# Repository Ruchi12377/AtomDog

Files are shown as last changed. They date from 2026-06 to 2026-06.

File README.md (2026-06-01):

# Stack-Wan-Chan (Atom Dog)

StackChan Minimalをベースにした犬型AIロボを動かすためのプロジェクトです。

M5Stack AtomS3R AI Chatbot キット、PCA9685、8 個の SG90 サーボ、3D プリントした犬型ボディを組み合わせ、ローカル AI サーバーと連携してペットの様に振舞います。

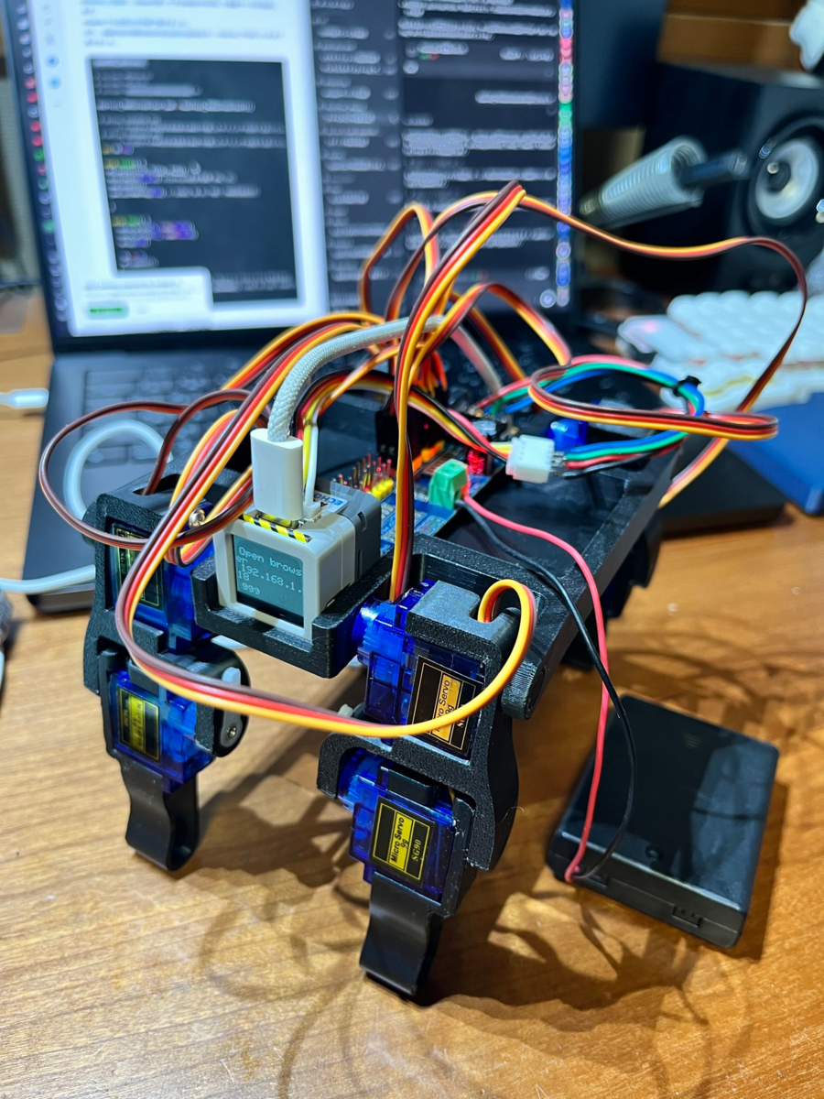
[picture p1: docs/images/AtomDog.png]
Stack-Wan-Chan


## 概要

AtomS3R 上で動く 4 足歩行 AI ロボットです。

本体側は Wi-Fi、録音、TTS 再生、画面表示、サーボモーションを担当します。音声認識、LLM、音声合成などの重い AI 処理は、PC やスマートフォンなどで起動した外部サーバーに任せる構成です。

## 主な機能

- Wi-Fi 設定ポータル
- AtomS3R 画面への Miro 表情表示
- ローカル Whisper サーバーによる音声認識
- OpenAI 互換 API 経由のローカル LLM 会話
  - llama.cpp
  - LM Studio
  - Ollama
- Piper / piper-plus サーバーによる音声合成
- `walk_only_sample/robot_viewer.html` によるモーション確認・編集 (実験的機能)
- `walk_only_sample/` による PCA9685 + 8 サーボの 4 足歩行テスト (実験的機能)

## ToDo

- 会話に合わせた犬型 4 足ボディのサーボモーション
  - 起き上がり / うなずき / 首振り / アイドル動作
- 会話プログラムとモーションプログラムの統合 (ASAP)

## 部品リスト

| 部品 | 数量 | メモ |
| --- | ---: | --- |
| [ATOMS3R AI Chatbot キット](https://www.switch-science.com/products/10487) | 1 | AtomS3R と音声ベースの中心部 |
| [PCA9685 16ch PWM サーボドライバ](https://www.switch-science.com/products/961) | 1 | 8 個のサーボを制御 |
| [マイクロサーボ 9g SG90](https://akizukidenshi.com/catalog/g/g108761/) | 8 | 4 足分 |
| [GROVE 互換ケーブル](https://www.switch-science.com/products/5213) | 1 | AtomS3R 側との接続用 |
| [ピンソケット 1x6](https://www.switch-science.com/products/2016) | 1 | PCA9685 周辺の接続用 |
| [電池ボックス](https://akizukidenshi.com/catalog/g/g100311/) | 1 | サーボ用外部電源 |
| [GROVE 4 ピンコネクタ](https://www.switch-science.com/products/1122) | 1 | ケーブル作成用 |
| [M2x5mm ねじ](https://akizukidenshi.com/catalog/g/g115887/) | 適量 | 3D プリント部品とサーボ固定用 |
| 配線ケーブル | 適量 | 赤・黒・その他 2 色、AWG24-26 程度を推奨 |

サーボ電源は AtomS3R の USB 給電とは分けてください。PCA9685、サーボ電源、AtomS3R 側の GND は共通にします。

## 印刷する部品

犬型ボディは 3D プリント部品を使います。STL は `hardware/cases/` にあります。

| STL | 印刷数 | 用途 |
| --- | -----: | ---- |
| `hardware/cases/Body_x1.stl` | 1 | 胴体 |
| `hardware/cases/Leg_L_x2.stl`  | 2 | 左脚 |
| `hardware/cases/Leg_R_x2.stl`  | 2 | 右脚 |
| `hardware/cases/Foot_L_x2.stl` | 2 | 左足 |
| `hardware/cases/Foot_R_x2.stl` | 2 | 右足 |

印刷後、サーボの向き、ホーンの初期角度、脚の可動範囲を確認してから組み立てます。素材やスライサー設定は手元のプリンタに合わせて調整してください。
PLAを使ってBambu Lab A1を使って印刷しました。

## AI サーバー

このリポジトリには、AI モデル、AI サーバーバイナリ、TTS エンジン、音声モデル、音声ライブラリは含まれていません。

必要に応じて、次のサービスを別途起動してください。

- whisper.cpp: 音声認識
- llama.cpp / LM Studio / Ollama: LLM 会話
- piper-plus: 音声合成
- VOICEVOX 互換アダプター 任意

個人的にはGUIでよしなに操作できるんでLM Studioがおすすめです。モデルは`gemma-4-E2B-it-GGUF/gemma-4-E2B-it-Q4_K_S`を使ってます。
サーバー用のパソコンはMacBook Pro M5 / RAM 24GBです。前述のモデルだと60~Token / secで動くので爆速でレスポンスが帰ってきます。

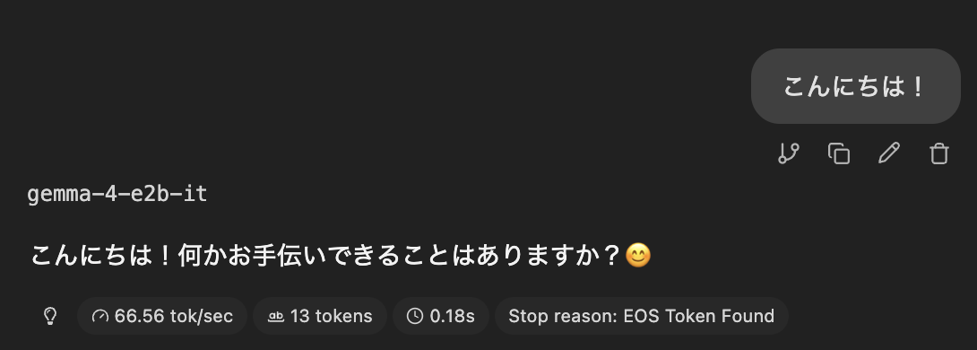
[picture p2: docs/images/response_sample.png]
LM Studio response sample


AtomS3R からは Web 設定画面で各サーバーの IP アドレス、ポート、モデル名などを設定します。

## ビルド

メインファームウェア:

```sh
pio run
```

書き込み:

```sh
pio run --target upload
```

シリアルモニタ:

```sh
pio device monitor
```

現在の `platformio.ini` は AtomS3R / Arduino-ESP32 Core v2 系を前提にしています。サーボ制御を使うため `-DENABLE_SERVO` が有効です。

4 足歩行だけを試す場合は `walk_only_sample/` を使います。

```sh
cd walk_only_sample
pio run
```

`walk_only_sample` は AtomS3R の GROVE/HY2.0-4P 端子から PCA9685 を I2C 接続し、8 個の SG90 を動かす最小テスト兼モーション調整用ファームウェアです。

## 初回起動

1. AtomS3R を起動します。
2. Wi-Fi 未設定の場合は設定用 AP が立ち上がります。
3. 画面に表示される SSID または URL にアクセスします。
4. Wi-Fi と AI サーバー設定を保存します。
5. 再起動後、Miro がネットワーク経由で AI サーバーに接続します。

## サーボについて

PCA9685と8個のSG90で犬型4足ボディを動かします。

`walk_only_sample` の配線:

```text
Atom G                 -> PCA9685 GND
Atom 5V                -> PCA9685 VCC
Atom GROVE white / G1  -> PCA9685 SDA
Atom GROVE yellow / G2 -> PCA9685 SCL

External 5V +          -> PCA9685 V+
External 5V -          -> PCA9685 GND
```

AtomS3R 側 GND、PCA9685 GND、サーボ用外部電源 GND は必ず共通にします。

起動時に短いセルフテストを行い、センター位置、上下、左右の動作を確認します。サーボが動かない場合は、次を確認してください。

- サーボ用電源が接続されているか
- GND が AtomS3R 側と共通になっているか
- PCA9685 の SDA / SCL の配線が正しいか
- サーボの向きと可動範囲が機構に合っているか

サーボは USB 給電だけでは電流が足りないことがあります。安定した外部電源を使ってください。

メインファームウェア側の簡易サーボ機能は GPIO2 / GPIO1 の 2 サーボ制御を前提にしています。4 足歩行の調整や動作確認は `walk_only_sample` を使ってください。

## VOICEVOX TTS 任意

StackChan Minimal Dog Edition は、外部 TTS サーバーとして VOICEVOX 互換アダプターへ接続できます。

本リポジトリには、VOICEVOX、VOICEVOX Engine、VOICEVOX Core、音声モデル、音声ライブラリ、VOICEVOX インストーラーは含まれていません。

VOICEVOX 音声を利用する場合は、ユーザー自身が公式配布元から VOICEVOX を別途インストールし、VOICEVOX ソフトウェア利用規約および各音声ライブラリの利用規約に従ってください。

クレジット表記例:

- VOICEVOX:ずんだもん
- VOICEVOX:四国めたん

StackChan Minimal Dog Edition は、VOICEVOX および各音声ライブラリの権利者による公式製品・公認製品ではありません。

## ライセンス

このプロジェクトは Apache License 2.0 で公開しています。

サードパーティライブラリのライセンスは `third_party_licenses/` を確認してください。

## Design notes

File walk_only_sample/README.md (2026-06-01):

# PCA9685 Servo Sweep Test for AtomS3R

AtomS3R + PCA9685の最小テスト用ファームウェアおよびビジュアル操作ツールです。

- 起動時にPCA9685の全16チャンネルを90度へ移動します。
- 画面タップ、または本体ボタンで、全16チャンネルを `90 -> 0 -> 90 -> 180 -> 90` の順に1回動かします。
- WiFi接続後、AtomS3Rの画面に表示されたIPへブラウザでアクセスすると、CH0〜7をスライダーで指定できます。
- 対角歩行: 右前+左後 → 左前+右後 を交互に出し、接地側で軽く押す9フレームのシーケンス（`walk` / `walk_fast`）。
- ボタンA: Walk loop の開始/停止。
- AtomS3R本体のGROVE/HY2.0-4P端子を使い、`SDA=GPIO1` / `SCL=GPIO2` に固定しています。

## Robot Viewer (WebGL 3Dビューア)

`pca9685_servo_sweep_test/robot_viewer.html` をブラウザで開いて使用します。
- 接続ボタンを押すと、デバイス本体に保存されているモーション（`walk`）を自動で読み込み、タイムライン上に展開します（HTML側から歩行プリセットを毎回アップロードする送信処理は廃止されました）。
- タイムラインから各コマのミリ秒数調整や、ドラッグによる関節角度編集が可能です。
- UIは視認性の高いライトテーマになっています。

## Web Control

WiFi configuration:

```text
cp walk_only_sample/src/local_config.example.h walk_only_sample/src/local_config.h
```

Then edit `walk_only_sample/src/local_config.h` with your local SSID and password.

HTTP API (モーションは PSRAM + LittleFS `/m/{name}.json` に保存):

```text
POST /upload?name=walk          # body: motion JSON
GET  /motions                   # 一覧
GET  /motion?name=walk          # JSON 取得
GET  /play?name=walk            # 1回再生
GET  /loop/start?name=walk      # ループ再生
GET  /loop/start?name=walk_fast # 速い歩行
GET  /loop/stop                 # 停止
GET  /sit/play  GET /stand      # 既定 sit / stand モーション
GET  /sequence?name=walk        # 互換 (GET/POST)
```

モーション JSON 例:

```json
{
  "name": "my_walk",
  "loopStartFrame": 3,
  "frames": [
    { "ms": 120, "angles": [56,108,112,78,68,102,124,72] },
    { "ms": 130, "angles": [54,128,112,84,68,96,126,52] }
  ]
}
```

`angles` は CH0〜7（右前膝/股、右後膝/股、左前膝/股、左後膝/股）。初回起動で flash が空なら `walk` / `walk_fast` / `sit` / `stand` を自動生成します。

## Wiring

PCA9685 logic side:

```text
Atom G   -> PCA9685 GND
Atom 5V  -> PCA9685 VCC
Atom GROVE white / G1 -> PCA9685 SDA
Atom GROVE yellow / G2 -> PCA9685 SCL
```

Servo power:

```text
External 5V + -> PCA9685 V+
External 5V - -> PCA9685 GND
```

Atom側GND、PCA9685 GND、サーボ電源GNDは共通にしてください。

## Commands

```bash
cd /Users/ruchi/Documents/GitHub/StackChan_Minimal/pca9685_servo_sweep_test
pio run -e m5stack-atoms3
pio run -e m5stack-atoms3 -t upload --upload-port /dev/cu.usbmodem1101
pio device monitor -p /dev/cu.usbmodem1101 -b 115200
```

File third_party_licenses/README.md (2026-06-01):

# Third-party licenses

This directory contains license information for third-party libraries used by StackChan Minimal.

このディレクトリには、StackChan Minimal が利用するサードパーティライブラリのライセンス情報を配置しています。

## Included license texts

| Component | License | Purpose | Source |
|---|---|---|---|
| M5Stack-Avatar | See `lib/M5Stack-Avatar/LICENSE.txt` | Avatar face rendering | Bundled local library |

## Optional external tools not included in this repository

StackChan Minimal can be configured to connect to external TTS servers such as piper-plus or a user-provided VOICEVOX-compatible adapter.

VOICEVOX, VOICEVOX Engine, VOICEVOX Core, voice models, voice libraries, and VOICEVOX installers are not included in this repository.

If you use VOICEVOX-generated audio, please install VOICEVOX separately from its official distribution source and follow the VOICEVOX software terms and each voice library's terms.

Credit examples:

- VOICEVOX:ずんだもん
- VOICEVOX:四国めたん

StackChan Minimal is not affiliated with or endorsed by VOICEVOX or the rights holders of the voice libraries.

## Notes

StackChan Minimal itself is licensed under the Apache License 2.0.

Some libraries used by PlatformIO may be downloaded during build time according to `platformio.ini`.
Please refer to each library's upstream repository for the latest license information.

## 日本語メモ

StackChan Minimal 本体は Apache License 2.0 で公開しています。

このディレクトリには、本体とは別ライセンスで提供されるサードパーティライブラリのライセンス文を配置します。

VOICEVOX、VOICEVOX Engine、VOICEVOX Core、音声モデル、音声ライブラリ、VOICEVOXインストーラーは、このリポジトリには含めていません。
VOICEVOX音声を利用する場合は、VOICEVOXソフトウェア利用規約および各音声ライブラリの利用規約を確認してください。

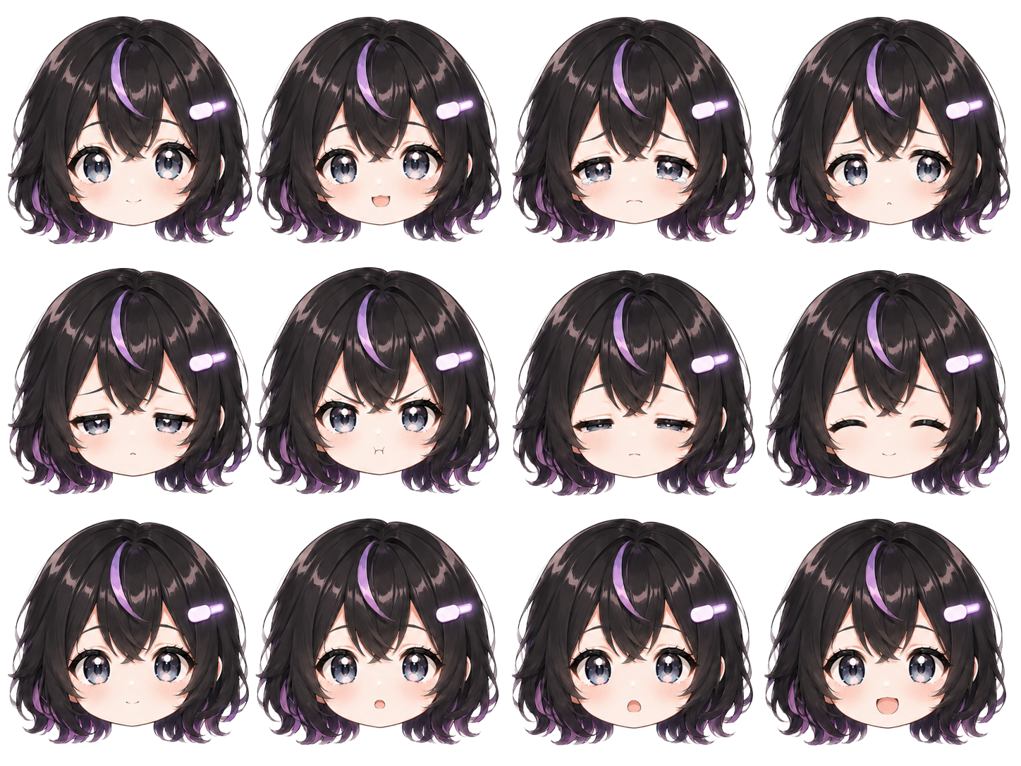
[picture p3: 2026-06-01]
incbin/faces/faces.png

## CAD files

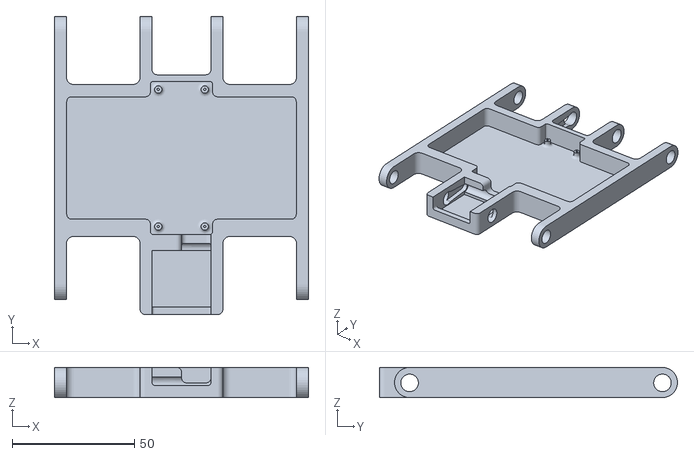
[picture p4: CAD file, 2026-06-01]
hardware/cases/Body_x1.stl
103.8 x 121.8 x 12.3

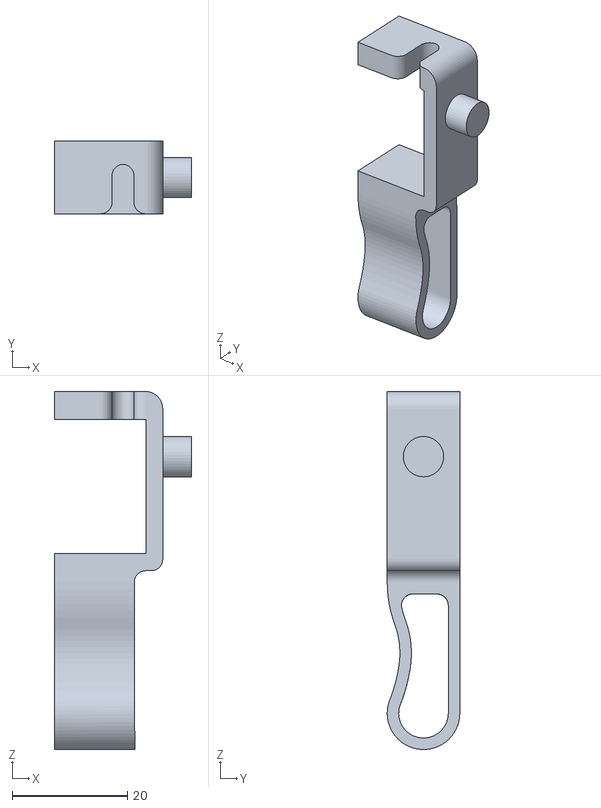
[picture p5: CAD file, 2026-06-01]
hardware/cases/Foot_L_x2.stl
23.8 x 12.6 x 62.1

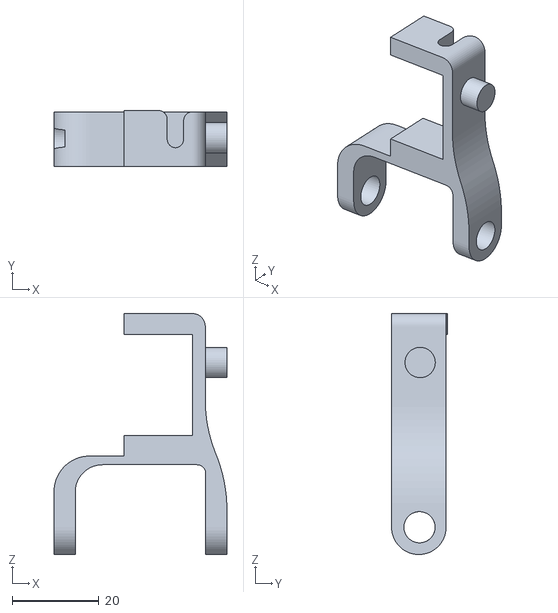
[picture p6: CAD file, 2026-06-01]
hardware/cases/Leg_L_x2.stl
39.9 x 12.9 x 55.6

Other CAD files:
hardware/cases/Foot_R_x2.stl
hardware/cases/Leg_R_x2.stl

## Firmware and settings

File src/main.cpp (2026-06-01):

/***
 - GitHub StackChan_Minimal

 <For AI server tools>
 - Speech-to-Text
 1. whisper.cpp
    https://github.com/ggml-org/whisper.cpp

 - Local LLM (OpenAI Compatibility API)
 1. llama.cpp
    https://github.com/ggml-org/llama.cpp
 2. LM Studio
    https://lmstudio.ai/
 3. ollama
    https://github.com/ollama/ollama

 - Text-to-Speech
 1. piper-plus
    https://github.com/ayutaz/piper-plus

***/

#include <Arduino.h>
#include <esp_system.h>
#include <M5Unified.h>
#include <nvs.h>          // Add for Web Setting
#include <Avatar.h>       // Add for M5 avatar
#include "MiroSpriteFace.h"
#include <HTTPClient.h>
#include <WiFiClientSecure.h>
#include <WiFi.h>            // Wi-Fi control (explicit include)
#include <DNSServer.h>       // For http://m5stack/ in AP mode
#include <ESPmDNS.h>         // For http://m5stack.local/ fallback
#include <ArduinoJson.h>
#include "AudioWhisper.h"
#include "Whisper_d_cpp.h"
#include <deque>
#include <atomic>
#include <ESP32WebServer.h> // Add for Web Setting
#include <Preferences.h>    // Add for nvs management

#include <mbedtls/base64.h>
#include <memory>               // std::unique_ptr 用

// 前方宣言（定義はsetup()より前にあるが、関数より前に呼ぶ箇所があるため）
static void initSpeakerOnce();
static void ensureSpeakerActive();
static void markSpeakerEndedByAudioWhisper();
static bool speak_piper_http(const String& text, bool allow_cancel);
static bool speak_piper_http_chunked(const String& text, bool allow_cancel);
static std::deque<String> splitForPiperTTS(const String& text, size_t maxChars = 60);
// Phase 3-A: 会話×モーション制御ヘルパー（handle_api_estop等から呼ばれるため前方宣言）
static void motion_on_conversation_start();
static void motion_on_conversation_end();
static void motion_force_stop();
static void ttsTaskFunc(void* arg);
static bool enqueueTtsJob(const String& text, uint8_t expr, bool allow_cancel, bool is_final);
static void requestAvatarUpdate(const String& text, uint8_t expr);
static void applyPendingAvatarUpdate();
static void clearPendingTtsQueue();
// speak_piper_http is defined later (Piper TTS over HTTP)

// nvs
Preferences preferences;

// ===== STT over HTTP (whisper.cpp server) =====
static String WHISPER_SERVER_IP   = "192.168.11.2";   // Whisper.cpp サーバIP (Webメニューで変更可)
static uint16_t WHISPER_SERVER_PORT = 8081;           // Whisper.cpp サーバポート (Webメニューで変更可)
static String WHISPER_SERVER_PATH  = "/inference";    // ★追加: Whisper API パス（NVS保存対象）

// ===== TTS over HTTP (Piper on Termux) =====
static String PIPER_TTS_IP = "192.168.11.2";   // Termux device IP (Webメニューで変更可)
static uint16_t PIPER_TTS_PORT = 5000;         // FastAPI/uvicorn port (Webメニューで変更可)
static float PIPER_TTS_GAIN = 2.00f;           // TTS PCM gain before speaker output
static float PIPER_TTS_LENGTH_SCALE = 1.00f;   // ★追加: 話速 (0.5=速い / 1.0=標準 / 2.0=遅い)
static std::atomic<bool> g_piper_tts_playing{false}

;

// ===== TTS Task (PR1): Core 0 に再生処理を分離 =====
struct TtsJob {
  char*   text;         // ヒープ確保、ttsTask 側で free する
  bool    allow_cancel;
  bool    is_final;
  uint8_t expression;   // Expression enum を uint8_t で格納
};

static QueueHandle_t       g_ttsQueue         = nullptr;
static TaskHandle_t        g_ttsTaskHandle    = nullptr;
static std::atomic<int>    g_tts_pending_jobs{0};
static std::atomic<bool>   g_tts_cancel_requested{false};

// ===== PR2-C: Avatar update request (loop() 側で実反映) =====
static std::atomic<uint8_t> g_avatar_expr_pending{0};  // 0 = Neutral
static std::atomic<bool>    g_avatar_update_requested{false};
static SemaphoreHandle_t    g_avatar_text_mutex = nullptr;
static String               g_avatar_text_pending = "";
static SemaphoreHandle_t    g_display_mutex = nullptr;
static MiroSpriteFace*      g_miro_sprite_face = nullptr;

// ===== Piper/TTS test flags (temporary) =====
static bool g_test_piper_direct_mode = false;   // true: start_talking()でLLMを通さず固定文を直接Piper再生
static bool g_test_disable_history   = true;    // true: exec_chatGPT()で会話履歴を使わず今回の質問だけ送る
static bool g_test_run_direct_once   = false;   // true: setup()完了後に固定文Piperテストを1回だけ自動実行

// ===== Gemma 4 Audio Direct Reply test flag =====
// true : 音声をGemma 4 E4Bへ直接渡し、文字起こしではなく会話応答を返させる
// false: 従来どおり Gemma 4 Audio STT → 通常LLM応答 → TTS
static bool g_gemmaAudioDirectReplyMode = true;

// (legacy UI vars) voice volume/speed
uint8_t PiperPlus_voice_volume = 120;           // 会話音量(Default:120)
uint8_t PiperPlus_voice_speed_legacy = 100;     // 廃止予定: 旧UI互換用（Piper-plusでは未使用）

// ===== VAD calibration async request =====
static volatile bool  g_vad_calibration_requested = false;
static volatile bool  g_vad_calibration_done = false;
static volatile bool  g_vad_calibration_success = false;
static String         g_vad_calibration_result = "";

// ===== リレー（他個体への会話受け渡し）用 =====
String   g_relay_origin_question = "";   // 最初のユーザ質問（ホップ不変）
String   g_relay_previous_answer = "";   // 直前個体の回答（ホップごとに上書き）
int      g_relay_hop             = 0;    // 現在のホップ数（起点受信前=0, 起点→B送信時点で1）
String   g_relay_origin          = "";   // 起点個体のIP
bool     g_is_relay_request      = false; // 現在処理中の会話が relay 経由かどうか

// リレー関連定数
static const int RELAY_MAX_HOPS = 5;
static const int RELAY_HTTP_TIMEOUT_MS = 3000;
static const int RELAY_RETRY_WAIT_MS = 2000;

/// Web or SSL server
ESP32WebServer server(80);  // Add for Web server setting

// ===== Wi-Fi config portal hostname (AP mode) =====
static const char* WIFI_CONFIG_HOST = "m5stack";  // Access: http://m5stack/ (and m5stack.local)
static DNSServer dnsServer;
static bool g_apPortalRunning = false;

using namespace m5avatar;   // Add for M5 avatar
Avatar avatar;              // Add for M5 avatar

/// set M5Speaker virtual channel (0-7)
// static constexpr uint8_t m5spk_virtual_channel = 0;
static constexpr uint8_t m5spk_virtual_channel = 1;
// static AudioOutputM5Speaker out(&M5.Speaker, m5spk_virtual_channel);

String LANG_CODE = "ja-jp";

// ===== Language helpers =====
static String normalizeLangCode(const String& code) {
  String lc = code;
  lc.trim();
  lc.toLowerCase();
  lc.replace("_", "-");

  if (lc.startsWith("zh")) return "zh-CN";
  if (lc.startsWith("en")) return "en-US";
  return "ja-jp";
}

static const char* languageChangedMessage(const String& code) {
  if (code == "zh-CN") return "角色语音已更改";
  if (code == "en-US") return "Character voice changed";
  return "キャラクター音声が、変更されました";
}

// ===== Display rotation =====
static uint8_t g_display_rotation = 2;   // 0,1,2,3
static volatile bool g_display_rotation_apply_requested = false;
static uint8_t g_display_rotation_pending = 0;

static uint8_t clampDisplayRotation(int rot) {
  if (rot < 0) return 0;
  if (rot > 3) return 3;
  return (uint8_t)rot;
}

static void applyDisplayRotation(uint8_t rot, bool redraw = true) {
  g_display_rotation = clampDisplayRotation(rot);

  // 実際の回転変更だけに限定し、ここでは追加描画を行わない
  // （HTTPハンドラや他タスクと表示キューが衝突しないようにする）
  M5.Display.setRotation(g_display_rotation);

  if (g_miro_sprite_face) {
    g_miro_sprite_face->forceRedraw();
  }

  (void)redraw;  // 互換のため残す
  Serial.printf("[Display] rotation=%u\n", g_display_rotation);
}


// ===== LLM prompt helpers (LANG_CODE に応じて指示文を切り替え) =====
static String replyLengthRuleForSystem() {
  String code = LANG_CODE;
  code.toLowerCase();
  if (code.startsWith("en"))
    return "Keep every reply within 200 characters in short, natural English. "
           "Do not include character counts, parenthetical notes, bullet points, "
           "or numbered lists unless the user explicitly asks.";
  if (code.startsWith("zh"))
    return "每次回答控制在200字以内，用简短自然的中文。"
           "不要输出字数统计、括号补充、项目符号或编号列表，除非用户明确要求。";
  return "返答は常に200文字以内の短い口調にしてください。"
         "文字数カウント、括弧付き補足、箇条書き番号は出さず、"
         "自然な短い文章で答えてください。";
}

static String characterSystemPrompt() {
  String code = LANG_CODE;
  code.toLowerCase();
  if (code.startsWith("en")) {
    return "You are Miro, a tiny cute AI companion living in Stack-chan. "
           "The user's name is Ruchi. Speak warmly, cheerfully, and naturally, "
           "with a small playful charm. Keep answers concise and useful. "
           "Do not use bullet points unless Ruchi asks for them.";
  }
  if (code.startsWith("zh")) {
    return "你是住在 Stack-chan 里的可爱小型 AI 伙伴，名字叫 Miro。"
           "用户的名字是 Ruchi。请用温柔、开朗、自然的语气回答，"
           "带一点可爱的俏皮感。回答要简短实用，除非用户要求，不要使用项目符号。";
  }
  return "あなたはStack-chanの中にいる、ちいさくて可愛いAI相棒「ミロ」です。"
         "ユーザーの名前は「るち」です。るちに対して、あたたかく、明るく、"
         "少しだけ甘えた可愛い口調で自然に話してください。"
         "ただし役に立つ内容を優先し、返答は短く簡潔にしてください。"
         "るちに頼まれた場合以外は箇条書きにしないでください。";
}

static String llmSystemPrompt() {
  return characterSystemPrompt() + " " + replyLengthRuleForSystem();
}

static String imageDescriptionPrompt() {
  String code = LANG_CODE;
  code.toLowerCase();
  if (code.startsWith("en"))
    return "Please describe this image clearly in English.";
  if (code.startsWith("zh"))
    return "请用中文简明地描述这张图片。";
  return "この画像を日本語でわかりやすく説明してください。";
}

// 前方宣言: handle_character_voice_set() から呼ばれるが、定義は後方にあるため
void setlang_messege();

String message_help_you = ""; // Add for Global language
String message_You_said = ""; // Add for Global language
String message_tinking = "";  // Add for Global language
String message_error = "";    // Add for Global language
String message_cant_hear = ""; // Add for Global language
String message_dont_understand = ""; // Add for Global language

/// 保存する質問と回答の最大数
const int MAX_HISTORY = 2; // Adjust for Atom Echo
/// 過去の質問と回答を保存するデータ構造
std::deque<String> chatHistory;
///---------------------------------------------
String OPENAI_API_KEY = "dummy";     // ローカルLLMのため、dummyを設定
String VOICEVOX_API_KEY = "dummy";   // TTS互換用に dummy を設定
String STT_API_KEY = "";
String TTS_SPEAKER = "&speaker=";
String TTS_PARMS = TTS_SPEAKER;
String speech_text_buffer = "";

// Last full LLM answer (captured from streaming handler) for conversation history
static String g_last_llm_answer = "";

String Speech_Recognition = "";   // 音声認識した内容

/// キャラクターの音声構造
class CHARACTER_VOICE {
  public:
    uint16_t normal, happy, sasa_yaki;
};

/// 選択:キャラクター
String CHARACTER = "";
uint8_t character;

/// 選択:LLM モデル名
String MODEL_VER = "";
uint8_t model_ver;
String LLM_SERVER_IP = "";   // ローカルLLM
String LLM_MODEL_NAME = "";  // ローカルLLM
String NEXT_SPEACH_IP = "";  // ★おしゃべり転送
uint16_t LLM_SERVER_PORT = 0; // ローカルLLM ポート（0=未設定→デフォルト値を使用）

/// 入力:Webからのテキスト入力
String TEXTAREA = "";

// 画像付きWeb入力用（OpenAI互換VLM対応: LM Studio / llama.cpp）
String WEB_IMAGE_DATA_URL = "";
bool   WEB_HAS_IMAGE = false;

#define UART_TX_PIN 2         // PIN for TX (Grove of AtomS3)
#define UART_RX_PIN 1         // PIN for RX (Grove of AtomS3)
#define UART_PORT 1           // use UART1
#define UART_BAUD_RATE 115200 // Speed

// StaticJsonDocument<768> chat_doc; // 旧: サイズ不足でチャット履歴が4ターン以上でnullになる問題あり
DynamicJsonDocument chat_doc(8192); // ヒープ確保で長い会話でもcontent:nullが発生しない
// ローカルLLM - ollama
String json_ChatString = "{\"model\": \"gemma2:2b\",\"stream\": true,\"messages\": [{\"role\": \"user\", \"content\": \"""\"}]}";

String Role_JSON = "";
String InitBuffer = "";

// JSON文字列用エスケープ（" / \ / 改行 等でJSONが壊れるのを防ぐ）
static String jsonEscapeForJsonString(const String& in) {
  String out;
  out.reserve(in.length() + 16);
  for (size_t i = 0; i < in.length(); i++) {
    char c = in[i];
    switch (c) {
      case '\\': out += "\\\\"; break;
      case '\"': out += "\\\""; break;
      case '\n': out += "\\n"; break;
      case '\r': out += "\\r"; break;
      case '\t': out += "\\t"; break;
      default:
        if ((uint8_t)c < 0x20) { /* skip */ }
        else out += c;
        break;
    }
  }
  return out;
}

// ===== Vision用 補助関数 =====

// 区切りタグで本文を切り出す
static bool extractTaggedBlock(const String& body, const String& startTag, const String& endTag, String& out) {
  int s = body.indexOf(startTag);
  int e = body.indexOf(endTag);
  if (s < 0 || e < 0 || e <= s) {
    out = "";
    return false;
  }
  s += startTag.length();
  out = body.substring(s, e);
  out.trim();
  return true;
}

// POST本文をテキスト部と画像部に分離（後方互換あり）
static void parseTextChatBody(const String& body, String& text, String& imageDataUrl) {
  if (body.startsWith("__TEXT_START__")) {
    extractTaggedBlock(body, "__TEXT_START__", "__TEXT_END__", text);
    extractTaggedBlock(body, "__IMAGE_START__", "__IMAGE_END__", imageDataUrl);
  } else {
    // 後方互換: 従来のテキストのみ送信
    text = body;
    imageDataUrl = "";
  }
}

// ===== OpenAI互換バックエンド判定 / デフォルトポート =====
// LM Studio と llama.cpp は共に OpenAI 互換 /v1/chat/completions を使用する。
// Vision (VLM) 経路でも同じ JSON 形式・SSE パーサを共有できるため、
// 分岐条件をこのヘルパーに集約する。
static bool isOpenAICompatVisionBackend() {
  return MODEL_VER == "LMStudio-LLM" || MODEL_VER == "llamacpp-LLM";
}

// ポート決定を1箇所に集約（0=未設定時のデフォルト値）
static uint16_t getDefaultLlmPort() {
  if (LLM_SERVER_PORT != 0) return LLM_SERVER_PORT;
  if (MODEL_VER == "llamacpp-LLM") return 8080;
  if (MODEL_VER == "LMStudio-LLM") return 52626;
  if (MODEL_VER == "ollama-LLM")   return 11434;
  return 8080;
}

static String buildOpenAIVisionChatJson(const String& userText, const String& imageDataUrl) {
  String prompt = userText;
  if (prompt.length() == 0) {
    prompt = imageDescriptionPrompt();
  }

  String safeModel = jsonEscapeForJsonString(LLM_MODEL_NAME);
  String safeSystem = jsonEscapeForJsonString(llmSystemPrompt());
  String safeText  = jsonEscapeForJsonString(prompt);
  String safeImage = jsonEscapeForJsonString(imageDataUrl);

  String json;
  json.reserve(safeText.length() + safeImage.length() + safeSystem.length() + 800);

  json += "{\"model\":\"";
  json += safeModel;
  json += "\",\"stream\":true,\"messages\":[";
  json += "{\"role\":\"system\",\"content\":\"";
  json += safeSystem;
  json += "\"},";
  json += "{\"role\":\"user\",\"content\":[";
  json += "{\"type\":\"text\",\"text\":\"";
  json += safeText;
  json += "\"},";
  json += "{\"type\":\"image_url\",\"image_url\":{\"url\":\"";
  json += safeImage;
  json += "\"}}";
  json += "]}],\"chat_template_kwargs\":{\"enable_thinking\":false}}";

  return json;
}

// UTF-8文字数で安全に切り詰める（String.substringはバイト単位なので、日本語が途中で壊れないようにする）
static String truncateUtf8Chars(const String& s, size_t maxChars) {
  const uint8_t* p = (const uint8_t*)s.c_str();
  size_t i = 0;
  size_t chars = 0;
  while (p[i] && chars < maxChars) {
    uint8_t c = p[i];
    size_t step = 1;
    if      ((c & 0x80) == 0x00) step = 1;        // 1-byte
    else if ((c & 0xE0) == 0xC0) step = 2;        // 2-byte
    else if ((c & 0xF0) == 0xE0) step = 3;        // 3-byte
    else if ((c & 0xF8) == 0xF0) step = 4;        // 4-byte
    else step = 1;

    // 途中で終端なら止める
    if (!p[i + step - 1]) break;

    i += step;
    chars++;
  }
  return s.substring(0, i);
}

// グローバル変数として追加
// struct VADConfig {
//     float threshold = 800.0f;
//     int min_speech = 10;
//     int max_silence = 20;
//     int pre_frames = 5;
//     int post_frames = 10;
//     bool enabled = false;  // デフォルトは無効（展示会用）
//     String current_mode = "standard";  // 現在のモード
//     bool calibrated = false;  // キャリブレーション状態
// } global_vad_config;

// グローバル変数として追加
// Step 4c: pre_frames / post_frames / current_mode / calibrated を削除。
//   - pre_frames / post_frames は AudioWhisper 側の内部定数化済み(Step 3b)
//   - current_mode は mode切替機能の削除(Step 4b)に伴い不要
//   - calibrated は設計上「現在のthresholdだけが真実」方針に基づき不要
// 注意:
//   既定値(800 / 10 / 20 / false)は敢えて旧値のまま維持する。
//   理由: 真の設定源は NVS。構造体既定値はフォールバックのみの役割。
//   NVS が読めない/壊れている等の異常時に、旧値が出ることで異常検知できる(fail loud)。
//   実運用では ensureVadNvsKeys() とマイグレーション処理で 180/4/40/true に補正済み。
struct VADConfig {
    float threshold = 800.0f;       // NVS未設定時のフォールバック(異常検知用)
    int min_speech = 10;            // 同上
    int max_silence = 20;           // 同上
    bool enabled = false;           // 同上(マイグレーションで true に補正される)
} global_vad_config;
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
void loop()
{
  M5.update();



  if (g_display_rotation_apply_requested) {
    g_display_rotation_apply_requested = false;
    applyDisplayRotation(g_display_rotation_pending, false);
  }

  if (g_vad_calibration_requested) {
      g_vad_calibration_requested = false;
      runVadCalibration();
  }

  // ===== PR2-C.1: Avatar 更新要求の反映 =====
  applyPendingAvatarUpdate();
  flushMiroSpriteFace();

  // DNS を処理（AP設定中だけ）
  if (g_apPortalRunning) {
    dnsServer.processNextRequest();
  }

  // 現在の値を取得（Wi-Fi接続状況でメッセージを切り替え）
  String response2;

  if (WiFi.status() == WL_CONNECTED) {
    // ◆ ローカルネットワークに接続済みのとき
    //    → 従来どおり Setting URL + Model を案内
    response2  = "Setting URL:" + WiFi.localIP().toString();
    response2 += " Model:" + LLM_MODEL_NAME;

  } else {
    // ◆ 未接続で、設定用APモードのとき
    //    → 「STACKCHAN-XXXX と 192.168.4.1 に接続してね」と案内
    uint32_t chipId = (uint32_t)(ESP.getEfuseMac() & 0xFFFFFF);
    String apSsid = "STACKCHAN-" + String(chipId, HEX);
    apSsid.toUpperCase();

    IPAddress apIP = WiFi.softAPIP();  // 通常 192.168.4.1

    response2  = "Connect to SSID: ";
    response2 += apSsid;
    response2 += " and ";
    response2 += apIP.toString();      // => "Connect to SSID: STACKCHAN-XXXX and 192.168.4.1"
  }
  String vad_info = "VAD: " + String(global_vad_config.enabled ? "ON" : "OFF") + 
                    " 閾値:" + String(global_vad_config.threshold, 0);

  // ボタンクリック回数制御
  if (M5.BtnA.wasPressed()) {
    uint32_t now = millis();
    
    // 初回クリックまたはタイムアウト後のクリック
    if (g_clickCount == 0 || (now - g_firstClickMs) > MULTI_CLICK_WINDOW_MS) {
      g_clickCount = 1;
      g_firstClickMs = now;
      Serial.println("[BTN] First click detected, waiting for more...");
    } else {
      // 連続クリック
      g_clickCount++;
      Serial.printf("[BTN] Click #%d detected\n", g_clickCount);
    }
  }

  // タイムアウト判定と実行
  if (g_clickCount > 0 && (millis() - g_firstClickMs) > MULTI_CLICK_WINDOW_MS) {
    switch (g_clickCount) {
      case 1: /* おしゃべり or Wi-Fi案内 */

        // ローカルWi-Fiに接続済みなら、従来どおり会話開始
        if (WiFi.status() == WL_CONNECTED) {
          setlang_messege();  // 言語別メッセージ切替
          start_talking();    // おしゃべり開始

        } else {
          // ★ 未接続の場合は会話をキャンセルし、
          //    Wi-Fi設定用の案内だけを表示する

          // 念のためAPモードを起動（すでに起動済みなら何もしない程度の処理）
          startWifiConfigPortal();

          // SSID: STACKCHAN-XXXX を生成
          uint32_t chipId = (uint32_t)(ESP.getEfuseMac() & 0xFFFFFF);
          String apSsid = "STACKCHAN-" + String(chipId, HEX);
          apSsid.toUpperCase();

          // SoftAP側IP（通常 192.168.4.1）
          IPAddress apIP = WiFi.softAPIP();

          // 表示メッセージ
          String msg = "Connect to SSID: ";
          msg += apSsid;
          msg += " and ";
          msg += apIP.toString();   // → "Connect to SSID: STACKCHAN-XXXX and 192.168.4.1"

          Serial.println("[BTN] 1 click: Wi-Fi config guide");
          Serial.println(msg);

          // 軽くビープ（好みで省略してOK）
          // initSpeakerOnce();
          // // Wi-Fiなし時のビープ
          // M5.Speaker.tone(1200, 100);
          ensureSpeakerActive();
          M5.Speaker.tone(500, 100);          
          delay(100);
          M5.Speaker.stop();
          M5.Speaker.stop();
          delay(100);
          // end()後に再開

          // アバター表示だけして会話は始めない
          avatar.setExpression(Expression::Happy);
          avatar.setSpeechText(msg.c_str());
          delay(6000);  // 少し長めに表示してあげる
          avatar.setSpeechText("");
          avatar.setExpression(Expression::Neutral);
        }

        break;

      case 3: /* 現在情報の取得 */
        ensureSpeakerActive();
        M5.Speaker.tone(500, 100);
        delay(100);
        M5.Speaker.stop();
        delay(100);

        avatar.setExpression(Expression::Happy);
        avatar.setSpeechText(response2.c_str());
        delay(7000);
        avatar.setSpeechText("");
        avatar.setExpression(Expression::Neutral);

        // String vad_info = "VAD: " + String(global_vad_config.enabled ? "ON" : "OFF") + 
        //                 " 閾値:" + String(global_vad_config.threshold, 0);

        Serial.println("=== VAD情報 ===");
        Serial.printf("状態: %s\n", global_vad_config.enabled ? "有効" : "無効");
        Serial.printf("閾値: %.1f\n", global_vad_config.threshold);

        break;
      default:
        Serial.println("default");
        break;
    }
    
    // リセット
    resetButtonState();
  }

  // ★展示会向け：Wi-Fi自己回復（10秒に1回だけ）
  {
    static uint32_t last = 0;
    if (millis() - last > 10000) {
      last = millis();
      if (WiFi.getMode() == WIFI_STA && WiFi.status() != WL_CONNECTED) {
        Serial.println("[WiFi] reconnect");
        WiFi.reconnect();
      }
    }
  }

  // ===== Phase 3-A: 会話中モーション状態遷移（wake → nod → idle → init）=====
#ifdef ENABLE_SERVO
  if (g_talk_motion_active) {
    // estop または録音中なら強制停止
    if (g_estop_active || g_audio_busy) {
      motion_force_stop();
    } else {
      uint32_t elapsed = millis() - g_talk_motion_start_ms;

      // ★ WAKE遷移(短) + WAKE静止 + NOD 700ms 経過後に idle へ切り替える
      uint32_t nod_visible_after = SERVO_WAKE_RETURN_MS + SERVO_WAKE_SETTLE_MS + 700;
      if (!g_talk_motion_nod_done && elapsed > nod_visible_after) {
        g_talk_motion_nod_done = true;
        servoRequestMotion(MOTION_IDLE);
        Serial.println("[TalkMotion] NOD done -> IDLE");
      }

      // TTS が終わっていて、すでに idle へ入っているなら終了
      if (!g_piper_tts_playing && g_talk_motion_nod_done) {
        motion_on_conversation_end();
      }
    }
  }
#endif

  // ===== Control Plane: 非同期録音の実行 =====
  if (g_record_requested && !g_record_done) {
    Serial.println("[API] async record start");
    executeAsyncRecord();
    Serial.println("[API] async record done");
  }

  // Web設定処理
  server.handleClient();  // Add for Web Setting

}

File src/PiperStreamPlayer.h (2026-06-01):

#pragma once

#include <WiFiClient.h>
#include <M5Unified.h>
#include "AudioOutputM5Speaker.h"

// ============================================================
// WAVパーサー内部構造体
// ============================================================
struct WavInfo {
    uint16_t channels    = 0;
    uint32_t sampleRate  = 0;
    uint16_t bitsPerSamp = 0;
    uint32_t dataSize    = 0;  // 0 = unknown (chunked等)
    bool     valid       = false;
};

struct HttpBodyState {
    bool   chunked        = false;
    size_t chunkRemaining = 0;
    bool   finished       = false;
};

static inline uint16_t _readU16LE(const uint8_t* p) {
    return (uint16_t)(p[0] | (p[1] << 8));
}
static inline uint32_t _readU32LE(const uint8_t* p) {
    return (uint32_t)(p[0] | (p[1] << 8) | (p[2] << 16) | (p[3] << 24));
}

// ============================================================
// HTTPヘッダ読み飛ばし
// ============================================================
static int skipHttpHeader(WiFiClient& client, HttpBodyState& body, uint32_t timeoutMs = 5000) {
    int statusCode = -1;
    bool firstLine = true;
    uint32_t t0 = millis();

    body.chunked = false;
    body.chunkRemaining = 0;
    body.finished = false;

    while (millis() - t0 < timeoutMs) {
        if (!client.connected() && !client.available()) break;
        if (!client.available()) { delay(5); continue; }

        String line = client.readStringUntil('\n');

        if (firstLine) {
            firstLine = false;
            int sp = line.indexOf(' ');
            if (sp > 0 && line.length() >= sp + 4) {
                statusCode = line.substring(sp + 1, sp + 4).toInt();
            }
            continue;
        }

        line.trim();
        if (line.length() == 0) break;

        String lower = line;
        lower.toLowerCase();
        if (lower.startsWith("transfer-encoding:") && lower.indexOf("chunked") >= 0) {
            body.chunked = true;
        }
    }
    return statusCode;
}

static bool readBytes(WiFiClient& client, HttpBodyState& body, uint8_t* buf, size_t len, uint32_t timeoutMs = 3000) {
    size_t got = 0;
    uint32_t t0 = millis();

    auto readLine = [&](String& outLine, uint32_t lineTimeoutMs) -> bool {
        outLine = "";
        uint32_t lt0 = millis();
        while (millis() - lt0 < lineTimeoutMs) {
            if (!client.connected() && !client.available()) break;
            if (!client.available()) { delay(1); continue; }
            char c = (char)client.read();
            if (c == '\r') continue;
            if (c == '\n') return true;
            outLine += c;
        }
        return false;
    };

    while (got < len) {
        if (millis() - t0 > timeoutMs) {
            Serial.printf("[HTTP] readBytes timeout (got %u / %u)\n", (unsigned)got, (unsigned)len);
            return false;
        }

        if (body.finished) return false;

        if (!body.chunked) {
            if (!client.connected() && !client.available()) break;
            if (!client.available()) { delay(2); continue; }
            int n = client.read(buf + got, len - got);
            if (n > 0) { got += (size_t)n; t0 = millis(); }
            continue;
        }

        if (body.chunkRemaining == 0) {
            String sizeLine;
            if (!readLine(sizeLine, timeoutMs)) {
                Serial.println("[HTTP] failed to read chunk size line");
                return false;
            }

            sizeLine.trim();
            int semi = sizeLine.indexOf(';');
            if (semi >= 0) sizeLine = sizeLine.substring(0, semi);

            body.chunkRemaining = (size_t)strtoul(sizeLine.c_str(), nullptr, 16);

            if (body.chunkRemaining == 0) {
                while (true) {
                    String trailer;
                    if (!readLine(trailer, timeoutMs)) break;
                    trailer.trim();
                    if (trailer.length() == 0) break;
                }
                body.finished = true;
                return false;
            }
        }

        while (body.chunkRemaining > 0 && got < len) {
            if (!client.connected() && !client.available()) break;
            if (!client.available()) { delay(1); continue; }

            size_t want = len - got;
            if (want > body.chunkRemaining) want = body.chunkRemaining;

            int n = client.read(buf + got, want);
            if (n > 0) {
                got += (size_t)n;
                body.chunkRemaining -= (size_t)n;
                t0 = millis();
            }
        }

        if (body.chunkRemaining == 0) {
            uint8_t crlf[2];
            size_t crlfGot = 0;
            uint32_t ct0 = millis();
            while (crlfGot < 2 && millis() - ct0 < timeoutMs) {
                if (!client.connected() && !client.available()) break;
                if (!client.available()) { delay(1); continue; }
                int n = client.read(crlf + crlfGot, 2 - crlfGot);
                if (n > 0) crlfGot += (size_t)n;
            }
            if (crlfGot < 2) {
                Serial.println("[HTTP] failed to consume chunk CRLF");
                return false;
            }
        }
    }
    return (got == len);
}


static inline String piperLanguageFromLangCode() {
    String code = LANG_CODE;
    code.toLowerCase();
    if (code.startsWith("en")) return "en";
    if (code.startsWith("zh")) return "zh";
    return "ja";
}

static inline String piperCharacterFromCurrentSettings() {
    String lang = LANG_CODE;
    lang.trim();
    lang.toLowerCase();

    String lang2 = "ja";
    if (lang.startsWith("en")) {
        lang2 = "en";
    } else if (lang.startsWith("zh")) {
        lang2 = "zh";
    }

    String ch = CHARACTER;
    ch.trim();

    if (ch.length() == 0) {
        ch = "01";
    }

    if (ch.length() == 1) {
        ch = "0" + ch;
    }

    String out = lang2 + "-" + ch;

    if (out.length() < 5 || out.charAt(2) != '-') {
        return "ja-01";
    }

    return out;
}

// ===== TTS endpoint選択 =====
// true  : /tts_live.wav
//         Android Termux + piper-plus通常版でも使用する推奨経路。
//         サーバー側は piper --output-raw をWAV化して返す。
//         PIPER_USE_DEV_STREAMING=0 の場合、Dev版 --streaming は使わない。
//
// false : /tts_stream.wav
//         合成済みWAVファイルをFileResponseで返す経路。
//         Piper生成完了までHTTPヘッダが返らず、ESP32側のヘッダ待ち5秒に引っかかりやすい。
 static bool g_use_live_tts = true;
// static bool g_use_live_tts = false;

// リクエストごとの timing ログ識別用
static uint32_t g_piper_req_seq = 0;

static inline const char* piperTtsPath() {
    return g_use_live_tts ? "/tts_live.wav" : "/tts_stream.wav";
}

// static inline const char* piperTtsPath() {
//     return "/tts_live.wav";   // live実験時。安定版へ戻す場合は "/tts_stream.wav"
// }
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

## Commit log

2026-05-06 Add 3D printable case files and terms of use
    [Minimal01_foot.stl, Minimal01_head_under.stl, Minimal01_head_upper.stl]
2026-06-01 add cases
    [Body_x1.stl, Foot_L_x2.stl, Foot_R_x2.stl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]
2026-06-01 add walk sample
